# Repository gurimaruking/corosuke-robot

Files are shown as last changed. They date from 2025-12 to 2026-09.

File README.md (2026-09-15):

# 🤖 Corosuke Robot / コロ助ロボット

> **C**ommunication-**O**riented **R**obot for **O**bserving, **S**upporting, and **U**nderstanding **K**ids' **E**veryday — that's **COROSUKE**.







A ~46 cm open-source animatronic of **Korosuke (コロ助)** from *Kiteretsu Daihyakka* — he
sees, listens, thinks, and talks in **Japanese or English**, emotes through his eyes, waves
his arms, and shuts himself down safely. Everything runs **100 % on-device on a D-Robotics
RDK X5**, with an ESP32-S3 driving the eyes and arms.

> 🏆 **D-Robotics Robotics Dream Keeper Challenge — Stage 3 (Launch)**
> 📄 [STAGE3.md](STAGE3.md) — showcase & benchmarks · 🧩 [PROPOSAL.md](PROPOSAL.md) · 🗺 [ROADMAP.md](ROADMAP.md)

<p align="center">
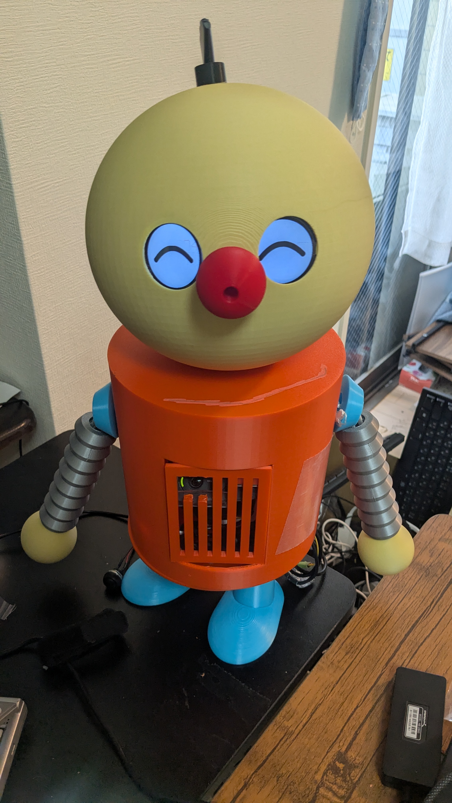
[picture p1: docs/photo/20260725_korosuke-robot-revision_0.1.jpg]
Corosuke revision 0.1 — fully assembled, smiling
  
</p>

## ▶ Watch the demo

<p align="center">
  <a href="https://youtu.be/NJwj6Iazd20">
    Watch the Corosuke demo on YouTube
  </a>
  <br>
  <a href="https://youtu.be/NJwj6Iazd20">
    
  </a>
</p>

---

## What it does

Powered on and left alone, Corosuke wakes and greets you, tracks you with BPU pose
detection, holds a conversation (on-device STT → LLM → TTS, with a "thinking" eye animation
while he ponders), reacts to gestures, waves his arms, and shuts down safely on a button
press (goodnight voice → ✕✕ "safe-to-unplug" eyes). A tabbed **web dashboard** at
`http://<board-ip>:8080` streams the live camera + skeleton and tunes every setting.

| Subsystem | Implementation | Measured |
|---|---|---|
| Vision | BPU YOLO11n-pose (Bayes-e `.bin`) | ~19.5 FPS |
| Speech-to-text | sherpa-onnx **SenseVoice** (JP/EN) + Silero VAD | real-time (CPU) |
| LLM dialogue | llama.cpp + TinySwallow-1.5B *(Qwen2.5-1.5B-based)* — JP & EN personas | 1.5–3.3 tok/s · ~5–10 s/reply |
| Text-to-speech | **JP** Open JTalk / **EN** espeak-ng | instant |
| Language | **日本語 / English** — STT · LLM · TTS · Web UI, switchable on the fly | on-device |
| Audio out | **MAX98357A I2S amp** (custom kernel driver) → φ50 speaker | DSP-tuned |
| Eyes | 2× GC9A01 on ESP32-S3 — 8 emotions (smile / thinking / ✕✕) | ≥30 FPS |
| Arms | 2× SG90 rope-pull bellows arms | auto-detach |

> 🌐 **Bilingual & fully on-device.** One switch flips the whole robot — speech recognition,
> LLM replies, voice, *and* the dashboard — between **Japanese and English**, with **no cloud
> and no API keys**. The voice stack follows D-Robotics' own [RDK voice-interaction
> reference](https://developer.d-robotics.cc/magicbox_doc/en/algorithm-development/voice-interaction):
> **SenseVoice** ASR + a **Qwen2.5-1.5B**-family LLM (we run the Japanese-tuned
> **TinySwallow-1.5B** via llama.cpp on CPU).

### Build tools & jigs

To reproduce the body you'll also need:

| Tool | Purpose | Where to get |
|---|---|---|
| **Velcro tape** | attaching parts to the 3D-printed body | [Amazon](https://www.amazon.co.jp/dp/B0GJZJM4TG) |
| **Ultrasonic cutter** (or an alternative) | post-processing the 3D-printed parts — anything that melts plastic works, even a heated metal needle | AliExpress |
| **3D printer** | printing the parts! (we used a **Bambu Lab A1**; parts are within 18 cm, so an **A1 mini** should *just* fit) | — |
| **Double-sided tape** | bonding parts | — |
| **String** | moving the hands (rope-pull arms) | — |
| **Zip ties** | tuning the rope arms | [Daiso](https://jp.daisonet.com/products/4550480088891) |
| **Soldering iron** | a little soldering (power button, amp terminals, etc.) | — |
| **Breadboard** (small) | ESP32-S3 wiring | — |
| **Jumper wires** (M-M / M-F) | connecting the parts | — |

## Challenge journey — Stage 1 → 2 → 3

| Stage | Theme | What was proven | Doc |
|---|---|---|---|
| **1 — Ideation** | On-device perception | YOLO11 vision on the **RDK X5 BPU** (+ open-source [RDK X5 case](https://github.com/gurimaruking/rdk-x5-modular-case)) | [STAGE1.md](STAGE1.md) |
| **2 — Build** | System design | The **RDK X5 as the single cognitive core** under a **ROS 2 graph**; ESP32s become actuator sub-controllers | [PROPOSAL.md](PROPOSAL.md) |
| **3 — Launch** | Shipped robot | The full interactive Corosuke — sees / listens / thinks / talks / emotes, **bilingual**, 100 % on-device (this repo) | [STAGE3.md](STAGE3.md) |

Stage 1's BPU vision is still today's perception layer, and Stage 2's ROS 2 design ships as
[`ros2_ws/`](ros2_ws/) alongside the low-latency monolith.

## Quick start (on the RDK X5)

> All on-device. **No cloud, no API keys.** Perception on the BPU, dialogue on the CPU.

```bash
# 1) Clone
git clone https://github.com/gurimaruking/corosuke-robot.git && cd corosuke-robot

# 2) Flash the eye/arm co-MCU (ESP32-S3) — from the RDK X5 (uses the CH343 UART port)
cd firmware/corosuke_eyes && pio run -t upload && cd ../..

# 3) One-time: MAX98357A I2S amp — build the out-of-tree codec driver + device-tree overlay
#    Follow docs/rdk_x5_40pin_i2s_max98357a.md  (kernel headers are already on the board)

# 4a) Run the INTEGRATED demo (monolithic, low-latency) as a systemd service
sudo cp deploy/*.service /etc/systemd/system/
sudo systemctl daemon-reload && sudo systemctl enable --now korosuke-monitor korosuke-shutdown-btn
#     → open  http://<board-ip>:8080   (Monitor / Settings tabs)

# 4b) — or — run the MODULAR ROS 2 graph (same on-device stack: TinySwallow + Open JTalk, no cloud)
cd ros2_ws && colcon build && source install/setup.bash
ros2 launch korosuke_nodes korosuke.launch.py                  # vision → brain → eyes / dialogue → voice
ros2 launch korosuke_nodes korosuke.launch.py with_web:=true   # + rosbridge :9090 → open ros2_ws/src/korosuke_nodes/web/console.html
#   NB: eye path is HW-verified; full graph is code-complete but not yet run end-to-end (see STAGE3 §5.1)

# Safe shutdown:  hold the GPIO button ~1 s  → goodnight voice → ✕✕ eyes → OS halt → cut power.
```

**Models** (STT / LLM / YOLO `.bin`) download on the board — see
[stt_research.md](docs/stt_research.md) and [dialogue_stack_research.md](docs/dialogue_stack_research.md).
The LLM stays on the CPU **by design**: the X5 BPU cannot accelerate LLMs
([rdk_x5_bpu_llm.md](docs/rdk_x5_bpu_llm.md)), so replies take ~5–10 s — the "thinking" eyes
cover the wait.

## Repository layout

```
corosuke-robot/
├── STAGE3.md, PROPOSAL.md, ROADMAP.md   # showcase / Stage-2 design / roadmap
├── scripts/            # korosuke_monitor.py (integrated demo) · shutdown_button.py · fix_max98357a.sh
├── ros2_ws/            # ROS 2 graph: korosuke_msgs + korosuke_nodes (vision/brain/dialogue/voice/serial_bridge)
├── firmware/           # ESP32-S3 (PlatformIO): corosuke_eyes (eyes + arms) · max98357a (I2S driver)
├── deploy/             # systemd units + sudoers (auto-start, safe shutdown, audio self-heal)
├── hardware/3d_models/ # OpenSCAD body (color-split) + RDK X5 modular case
└── docs/               # architecture, audio(I2S), BPU-LLM, network, power/USB, research, photos, diary
```

## Documentation

- **[STAGE3.md](STAGE3.md)** — architecture (Mermaid), benchmarks, **known issues & limitations**, requirement coverage
- **Story / presentation** — intro blog [日本語](docs/blog/intro_ja.md) · [English](docs/blog/intro_en.md) · 5-min talk: [slides PDF](docs/slides/talk_5min.pdf) · [deck (PNG)](docs/slides/talk_5min_deck.md)
- Audio (I2S amp): [docs/rdk_x5_40pin_i2s_max98357a.md](docs/rdk_x5_40pin_i2s_max98357a.md) · [firmware/max98357a/](firmware/max98357a/)
- Why the LLM stays on CPU: [docs/rdk_x5_bpu_llm.md](docs/rdk_x5_bpu_llm.md)
- Network / maintenance: [docs/network_setup.md](docs/network_setup.md) · Power/USB brown-out: [docs/power_usb_troubleshooting.md](docs/power_usb_troubleshooting.md)
- Testing: [docs/TESTING.md](docs/TESTING.md) · Build log: [docs/diary/](docs/diary/)

## Credits & inspiration

Corosuke's design borrows ideas from these open / animatronic robots:

- [Disney's Olaf robot](https://thewaltdisneycompany.com/olaf-robotic-character/) — expressive animatronic eyes & face
- [Open Duck Mini (BDX)](https://github.com/apirrone/Open_Duck_Mini) — compact bipedal droid
- [3D-printed animatronic dual-eye mechanism](https://www.instructables.com/Simplified-3D-Printed-Animatronic-Dual-Eye-Mechani/) — the eye-rig approach

## License & disclaimer

MIT for the code/hardware — see [LICENSE](LICENSE). Fan-made, **non-commercial** tribute:
"Korosuke" (コロ助) is a character from *Kiteretsu Daihyakka* by Fujiko F. Fujio; all
character rights belong to their respective owners.

**「ワガハイはコロ助ナリ！」** 🤖

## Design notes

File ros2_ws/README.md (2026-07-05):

# Korosuke ROS 2 workspace (RDK X5 cognitive core)

Stage 3 の実装。RDK X5 (ROS 2 Humble) を頭脳に、コロ助が
**見る → 追う → 挨拶する → 表情/声で反応する** をオンデバイスで動かす。

## パッケージ
| pkg | 中身 |
|---|---|
| `korosuke_msgs` | `EyeCmd`(emotion/gaze/blink), `FacePose`(detected/x/y/size) |
| `korosuke_nodes` | `vision`(BPU YOLO11n→/face_pose), `brain`(追従+挨拶), `serial_bridge`(→ESP32目UART), `dialogue`(Claude+「ナリ」), `voice`(VOICEVOX), `eye_demo`(M2実証) |

## データフロー
```
camera ─► vision_node ─/face_pose─► brain_node ─/eye_cmd──► serial_bridge ─UART─► ESP32-S3(目)
                                        └────────/greet──► dialogue_node ─/say_text─► voice_node ─► spk
                                                             └─────────/eye_cmd──────► serial_bridge
```

## ビルド
```bash
source /opt/ros/humble/setup.bash
cd ~/corosuke/ros2_ws
colcon build --symlink-install
source install/setup.bash
```

## 実行
```bash
# 全部まとめて
ros2 launch korosuke_nodes korosuke.launch.py

# 目だけ動作実証(M2, カメラ/LLM不要)。ESP32-S3をUSB接続してから:
ros2 run korosuke_nodes serial_bridge &
ros2 run korosuke_nodes eye_demo

# 手入力でコロ助と会話(STT代わり)
ros2 topic pub --once /korosuke/user_text std_msgs/String "{data: 'コロッケ好き？'}"
```

## 前提
- `ANTHROPIC_API_KEY` を export すると LLM 応答。無ければ定型「ナリ」応答。
- VOICEVOX を `localhost:50021`(または `VOICEVOX_HOST`)で起動すると発声。無ければセリフ表示のみ。
- 目: `firmware/corosuke_eyes` を焼いた ESP32-S3 を USB 接続(テキスト行 115200bps)。

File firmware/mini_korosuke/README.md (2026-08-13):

# firmware/mini_korosuke — ミニコロ助 (ESP32-S3 単体 / 完全オフライン)

[docs/mini_korosuke_design.md](../../docs/mini_korosuke_design.md) の実装。
ベースボード = **Elecrow ESP Terminal 3.5"**（ESP32-S3, 320×480 ILI9488 SPI, 静電容量タッチ FT6236, OV2640 同梱, 16MB/8MB）。

目の描画は本体の [firmware/corosuke_eyes](../corosuke_eyes/src/main.cpp) から移植（丸型GC9A01×2 → 単画面ILI9488に左右2目）。

## フェーズ
| Ph | 内容 | 本ファイルの状態 |
|----|---|---|
| **Ph1** | 単画面に左右2目＋表情8種＋まばたき＋視線（デモ巡回） | ✅ `src/main.cpp` |
| Ph2 | 静電タッチ(なで)→笑顔＋MAX98357A(I2S)でWAV再生 | ⏳ 未 |
| Ph3 | OV2640＋ESP-WHO顔検出→視線追従＋発見で笑顔 | ⏳ 未 |

## ピン割り当て
**確定（Elecrow wiki）**
| 機能 | ピン |
|---|---|
| SD (SPI) | SCK=12 MOSI=13 MISO=14 CS=10 |
| Touch FT6236 (I2C) | SDA=2 SCL=1 |
| Buzzer | 45 |
| Mic (I2S) | CLK=39 WS=38 |
| Camera OV2640 | MCLK=7 PCLK=17 / D2..D9=8,47,48,21,18,16,15,6 |
| Crowtail | D=11,40 / A=19,20 / UART RX=44 TX=43 |

**★未確定（実機スキーマで要確認）— `src/main.cpp` 冒頭の `PIN_LCD_*`**
- LCD ILI9488 の **CS / DC / RST / BL**。本S3+カメラ版の確定値が未取得。
- LCDはSDと同一SPIバス（SCK12/MOSI13/MISO14）を共有する前提で設定済み。
- ネット上に出回る `CS15/DC2/BL27` は**旧ESP32(非S3)版**の値。**DC=2 は本機の Touch SDA=2 と衝突**するので流用不可。
- 現状の `PIN_LCD_CS=3 / DC=42 / RST=-1 / BL=46` は「確定ピンと衝突しない仮値」。**ボード到着後に必ず実測して修正**すること。

**Ph2の音声増設（予定）**: 在庫の MAX98357A を I2S で Crowtail の空きGPIO（D=11,40 ＋ A=19 等）へ。BCLK/LRCLK/DIN の3本。

## ビルド & 書き込み
```bash
pio run -e elecrow-esp-terminal-35 -t upload
pio device monitor -b 115200
```
※ ★未確定ピンを埋める前は正しく表示されない。まず `PIN_LCD_*` を実機で確定させること。

## シリアルコマンド（USB-CDC / 115200・センサ無しで動作確認可）
```
emo <neutral|happy|happy2|sad|angry|surprised|sleepy|thinking|x>
gaze <x> <y>     # -1.0..1.0
blink
wink <l|r>
idle <on|off>
demo <on|off>    # 表情8種を自動巡回(初期ON)
ping             # -> pong
```

## 音声クリップの用意（別途・PC/RDK側）
声質はコロ助と同一（`-fm 9 -a 0.40 -r 1.12`）。Open JTalk のある環境で:
```bash
python3 ../../tools/mini_voice_gen.py            # WAV + manifest.json + include/voice_clips.h を生成
python  ../../tools/mini_voice_gen.py --dry-run  # Windows等: 先にヘッダ/マニフェストだけ
```
生成物: `assets/mini_voice/*.wav`（microSDの `/voice/` に配置）と `include/voice_clips.h`（Ph2でincludeして使用）。

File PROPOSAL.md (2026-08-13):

# Project Korosuke — Stage 2 (Build): System Design

D-Robotics **Robotics Dream Keeper Challenge** — Stage 2 design document.
Korosuke (コロ助) is the samurai-robot from *Kiteretsu Daihyakka*, rebuilt as a
50 cm desktop animatronic whose brain is an **RDK X5** (10 TOPS BPU, ROS 2).

> **Status:** v1.0 (2026-07-05, submitted). Builds directly on the Stage 1 result
> ([STAGE1.md](STAGE1.md)) — on-device YOLO11 vision is already proven.
> **Key pivot documented here:** the original design (3× ESP32 + a home server
> doing the AI) is **re-wired** so the RDK X5 is the cognitive core and the ESP32s
> become its servo/actuator sub-controllers, all under a ROS 2 graph.
>
> ⚠️ **This is the Stage-2 *plan*, not the shipped robot.** Some proposed subsystems
> were **deferred / not built** — notably the **2-axis mouth & lip-sync**, the **neck servo**
> (gaze is eyes-only), **bipedal QDD walking** (stretch), and VOICEVOX was replaced by
> on-device Open JTalk TTS. See **[STAGE3.md §8](STAGE3.md#8-known-issues-limitations--failure-recovery)**
> for exactly what shipped vs. what was deferred.

---

## 1. Concept

### 1.1 What Korosuke does
A child-minded samurai robot that **sees, talks, emotes, and gestures** — and, as a
stretch, **walks**. He recognizes a person, turns to look, greets them in his
trademark "…nari" speech, shows emotion through large animated eyes, and reacts
with head/arm gestures. All perception and dialogue run **on-device** on the RDK X5.

### 1.2 Why RDK X5 at the center (the Stage-1 pivot)
The pre-challenge design pushed AI to an external home server and used 3 ESP32s as
peers. Stage 1 proved the RDK X5 can run the perception **on the board** (YOLO11n on
the BPU). Stage 2 therefore promotes the RDK X5 to the **single cognitive core** and
demotes the ESP32s to **dumb, real-time actuator drivers** it commands. This removes
the network round-trip from the perception loop and gives a clean ROS 2 architecture.

### 1.3 Measurable goals (acceptance criteria)
Grounded in Stage 1 measurements (live USB-cam YOLO11n **8.3 FPS end-to-end**, BPU
alone **~67 inferences/s**, idle **66 °C → ~49 °C** with the fan lid):

| # | Capability | Target (measurable) | Stage-1 basis |
|---|---|---|---|
| G1 | Vision (person/face) | ≥ 10 FPS sustained on BPU; detection→action latency < 150 ms | 8.3 FPS live, 67 FPS BPU headroom |
| G2 | Gaze / head tracking | Eyes + neck follow a face, error < 5° after 300 ms | new |
| G3 | Voice dialogue | wake → LLM → speech start < 3.0 s; "…nari" style 100% | server already implemented |
| G4 | Lip-sync | mouth follows audio envelope within 100 ms | protocol has LIPSYNC_DATA |
| G5 | Eye emotion | ≥ 30 FPS render on 2× GC9A01, 7 emotions | RoboEyes-class |
| G6 | Thermal under load | BPU+CPU+vision sustained < 60 °C | 50 °C @ 20 s BPU load (fan) |
| G7 | *(stretch)* Bipedal | quasi-static "penguin" gait, 3+ steps, no fall | QDD revival gated |

---

## 2. AI System Architecture

### 2.1 End-to-end data flow

```mermaid
flowchart LR
  CAM[USB / MIPI camera] --> VIS

  subgraph RDKX5["RDK X5 — cognitive core (Ubuntu 22.04 + ROS 2)"]
    VIS["vision_node<br/>BPU: YOLO11n + face"]
    BRAIN["ai_brain_node<br/>state machine + intent"]
    LLM["dialogue_node<br/>LLM (Claude/OpenAI) + 'nari' persona"]
    TTS["voice_node<br/>VOICEVOX (Zundamon) + lipsync envelope"]
    EXP["expression_node<br/>emotion -> eye/mouth cmds"]
    MOT["motion_node<br/>gaze + gesture + (stretch) gait"]
    BRIDGE["serial_bridge_node<br/>ROS2 <-> UART 0xAA..0x55"]
    MIC[I2S mic] --> LLM
    TTS --> SPK[I2S speaker/amp]
  end

  VIS -->|/person, /face_pose| BRAIN
  BRAIN --> LLM
  BRAIN --> MOT
  LLM --> TTS
  LLM -->|emotion| EXP
  TTS -->|/lipsync| EXP
  EXP --> BRIDGE
  MOT --> BRIDGE

  BRIDGE -->|UART| EYE["ESP32-S3 — eye coprocessor<br/>2× GC9A01 (RoboEyes)"]
  BRIDGE -->|UART| UP["ESP32 — upper body<br/>PCA9685: mouth/neck/arms"]
  BRIDGE -->|UART| LO["ESP32 — lower body<br/>servo/QDD + BNO055 IMU"]
  LO -->|/imu, /balance| BRAIN
```

### 2.2 ROS 2 node / topic graph

```mermaid
flowchart TD
  vision["/korosuke/vision_node"] -->|sensor_msgs/Image, vision_msgs/Detection2DArray| brain
  vision -->|geometry_msgs/PointStamped /face_pose| motion
  brain["/korosuke/ai_brain_node"] -->|std_msgs/String /intent| dialogue
  brain -->|/gaze_target| motion["/korosuke/motion_node"]
  dialogue["/korosuke/dialogue_node"] -->|/say_text| voice
  dialogue -->|/emotion| expression
  voice["/korosuke/voice_node"] -->|/lipsync_env| expression
  expression["/korosuke/expression_node"] -->|korosuke_msgs/EyeCmd, MouthCmd| bridge
  motion -->|korosuke_msgs/ServoCmd, GaitCmd| bridge
  bridge["/korosuke/serial_bridge_node"] -->|UART frames| mcus["ESP32 ×3 (eye/upper/lower)"]
  mcus -->|/imu, /status| bridge --> brain
```

**Custom messages** (`korosuke_msgs`): `EyeCmd` (gazeX, gazeY, emotion, blink),
`MouthCmd` (open 0-1), `ServoCmd` (joint id, angle), `GaitCmd` (step, dir),
`Detection` (label, score, bbox). The existing **`protocol.h` (0xAA…0x55)** frame
is kept as the wire format; `serial_bridge_node` serializes ROS 2 msgs to it, so
the ESP32 firmware barely changes.

### 2.3 Compute & resource allocation

RDK X5 = 8× Cortex-A55 (CPU), 10 TOPS BPU, 8 GB LPDDR4, Mali GPU.

| Engine | Workload | Budget | Notes |
|---|---|---|---|
| **BPU** | YOLO11n detection (+ face crop/landmarks) | ~15 % of 67 FPS headroom at 10 FPS | model already converted (Bayes-e .bin) |
| **CPU core 0-1** | ROS 2 DDS + node executors | moderate | Cyclone DDS |
| **CPU core 2-3** | dialogue_node (async LLM HTTP) + persona | I/O-bound | reuse `server/` code |
| **CPU core 4** | voice_node: VOICEVOX client + audio I2S + lipsync envelope | real-time audio | MAX98357A out, INMP441 in |
| **CPU core 5** | motion_node: gaze/gesture planning, (stretch) gait | light | |
| **CPU core 6-7** | serial_bridge + headroom | low | 3× UART @ 115200 |
| **ESP32-S3 (eyes)** | 2× GC9A01 @ ≥30 FPS, RoboEyes | dedicated MCU | off-loads display from RDK |
| **ESP32 (upper)** | PCA9685 #1: mouth/neck/arms, 50 Hz | dedicated MCU | existing firmware |
| **ESP32 (lower)** | servo/QDD + BNO055 100 Hz balance | dedicated MCU | existing skeleton |

**Thermal:** sustained BPU+CPU stays < 60 °C with the open-source **fan lid**
(5 V 40 mm fan off the 40-pin header) — validated in Stage 1.

---

## 3. Engineering Plan

### 3.1 Bill of Materials (summary)
This table is the canonical BOM. As-built hardware deltas for the shipped robot (φ50 speaker on a MAX98357A I2S amp, Logitech C270 camera, safe-power button, mic taken from the C270) are in [STAGE3.md](STAGE3.md).

| Subsystem | Part | Qty | Status |
|---|---|-----|---|
| Brain | RDK X5 8GB + open-source fan case | 1 | ✅ owned / case done |
| Eyes | GC9A01 1.28" 240×240 SPI | 2 | to buy (~¥2.4k) |
| Eye coproc | ESP32-S3 N16R8 | 1 | to buy (~¥2.5k) |
| Camera | UVC USB (Stage 1) → MIPI CSI (planned) | 1 | ✅ working |
| Face/neck/arms | PWM servos (SG90/MG996R) + PCA9685 ×2 | ~12 + 2 | ✅ in stock |
| Audio | INMP441 mic, MAX98357A amp + speaker | 1 set | ✅ in stock |
| IMU | BNO055 | 1 | ✅ in stock |
| Touch (head-pat) | TTP223 capacitive touch sensor | 1 | 🔜 planned — not yet installed |
| Body display (STT/reply view) | ESP32 CYD — Sunton ESP32-4827S043R 4.3" touch *(or ESP32-1732S019 1.9", auto-detected)* | 1 | ✅ working — shows camera + recognized speech + replies, language switch on touch |
| Legs *(stretch)* | SteadyWin GIM8108-36 QDD (CAN) | ≤8 | ⚠️ junk, unverified |
| Power | LiPo 3S/4S + DC-DC + AC adapter | — | ✅ in stock |

### 3.2 Proposed repository layout
```
corosuke/
  ros2_ws/src/                # NEW — the cognitive core
    korosuke_msgs/            # EyeCmd, MouthCmd, ServoCmd, GaitCmd, Detection
    korosuke_vision/          # BPU YOLO11 + face -> /person, /face_pose
    korosuke_brain/           # state machine + intent
    korosuke_dialogue/        # LLM + persona (port of server/corosuke_personality.py)
    korosuke_voice/           # VOICEVOX client + audio I/O + lipsync
    korosuke_expression/      # emotion -> eye/mouth
    korosuke_motion/          # gaze/gesture/(gait)
    korosuke_bridge/          # ROS2 <-> protocol.h UART
  firmware/                   # EXISTING — minor refactor (eye/upper/lower)
  server/                     # EXISTING — folded into korosuke_dialogue/voice
  hardware/3d_models/         # EXISTING — body + RDK X5 case
  docs/                       # this design, BOM, inventory, research
```

### 3.3 Roadmap (as of 2026-07-05 → hard deadline 2026-07-15)

**Done so far:** Stage 1 (BPU YOLO11 vision, thermal fan-lid, open-source RDK X5
case) ✅; full 3D body redesigned for color-split printing ✅; eye coprocessor
firmware flashed (2× GC9A01 on ESP32-S3, LovyanGFX) ✅; chest stereo-camera mount
designed ✅. See the live plan in [ROADMAP.md](ROADMAP.md).

| Window | Milestone | Exit criterion |
|---|---|---|
| **7/5–7/7** | ROS 2 Humble on RDK X5; `korosuke_msgs`; `serial_bridge` ↔ ESP32-S3 eyes | a ROS 2 topic makes the eyes blink / change emotion |
| **7/8–7/11** | `vision_node` (BPU) → `/face_pose`; gaze (eyes + neck) tracking; on-device dialogue loop (LLM + VOICEVOX) + lipsync; `expression_node` | Korosuke looks at a face and says a "…nari" line with lipsync |
| **7/12–7/13** | Integrated demo: see → turn → greet → emote → gesture, fully on-device; benchmark table (FPS / latency / thermal) | G1–G6 met; **competition-critical line complete** |
| **7/14–7/15** | 3–7 min demo video; Stage 3 showcase PR; bipedal stretch *iff* QDD revived | Stage 3 submission package |

### 3.4 Risk analysis

| # | Risk | Likelihood | Impact | Mitigation |
|---|---|---|---|---|
| R1 | **QDD GIM8108 are junk / dead** | high | high (no walking) | Bipedal is a **decoupled stretch**, never on the MVP critical path; MVP passes on a seated/standing torso |
| R2 | LLM/VOICEVOX latency or network drop | med | med | local response cache, canned "…nari" fallbacks, keep dialogue async off the perception loop |
| R3 | 2× GC9A01 @30 FPS too heavy for one MCU | med | med | dedicated **ESP32-S3 coprocessor** (not the RDK); RoboEyesTFT; drop to 240×240@30 per eye |
| R4 | Thermal throttling under multi-task | low | med | fan lid validated (−17 °C); monitor `hrut_somstatus` |
| R5 | Eye looks small (φ32 LCD in a 50 mm socket) | med | low | white diffuser ring + recessed mount in `corosuke_exterior.scad` |
| R6 | RoboEyes is **GPL-3.0** | low | med (licensing) | isolate eye firmware as a separate GPL component; keep core under its own license |
| R7 | Power budget if QDD added (high stall current) | med | med | separate LiPo rail + DC-DC (see BOM §3.1); current-limit; MVP runs on bench PSU |
| R8 | Timeline (7/8 is tight) | med | high | MVP-first decoupling; reuse existing firmware/server; this plan front-loads integration |

---

## 4. Reuse vs. new work

| Asset | Stage 1/pre status | Stage 2 action |
|---|---|---|
| `protocol.h` / `config.h` | complete | **reuse** as the RDK↔ESP32 wire format |
| `firmware/corosuke_main` | done (WiFi/cam/LLM) | **retire** — its brain role moves to RDK X5 |
| `firmware/corosuke_upper/lower` | skeletons | **refactor** into pure ROS2-driven servo nodes |
| `server/` (FastAPI+LLM+VOICEVOX) | done | **port** into `korosuke_dialogue`/`korosuke_voice` on-device |
| `corosuke_personality.py` ("…nari") | done | **reuse** verbatim |
| 3D body + RDK X5 case | done | **reuse**; only the eye socket needs tuning |
| BPU YOLO11n pipeline | proven (Stage 1) | **promote** into `vision_node` |

The heavy lifting is **re-wiring, not re-inventing** — most subsystems already exist;
Stage 2 puts the RDK X5 in charge and expresses the whole system as a ROS 2 graph.

---

*Assumptions to confirm with the team:* exact servo counts per joint (pending the
actuator-assignment table), whether the home server stays as a fallback or is fully
folded on-device, and the bipedal go/no-go once the QDD motors are bench-tested.

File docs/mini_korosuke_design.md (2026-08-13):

# ミニコロ助 — ESP32-S3 単体 設計書

**完全オフライン**で動く手のひらサイズの「コロ助」。RDK X5 を使わず **ESP32-S3 1枚**で
目の表情・なで反応・顔検出・「〜ナリ」音声までを完結させる派生機。
本体（[stage2_design.md](stage2_design.md)）の資産を **流用中心**で再構成する。

> 決定日: 2026-07-29 / 方針: 完全オフライン（no cloud・ネット不要）

---

## 1. スコープ（確定）

| 項目 | 決定 |
|---|---|
| しゃべり方式 | **完全オフライン**。LLM/STT/TTS は載せない（S3では不可能）。事前生成した「〜ナリ」WAV を再生 |
| 搭載機能 | 目の表情8種 ◎ / なで（タッチ）反応 ◎ / **カメラ顔検出→視線追従** |
| 見る | **あり**（カメラ付きS3ボードを使用） |
| 非搭載（今回） | 会話、音センサ反応（マイクは載るが未使用）、腕サーボ |
| ネット | 一切不要（ボード net不通・no cloud 原則を満たす） |

**S3単体で動かせない物（明示）:** TinySwallow-1.5B LLM / sherpa-onnx STT /
Open JTalk・VOICEVOX TTS。いずれも RDK/PC の CPU 前提。ミニ版は声を**事前生成**で回避する。

---

## 2. ハードウェア

### 2.1 ベースボード（推奨）
**Elecrow ESP Terminal 3.5"（OV2640 同梱）**

| 項目 | 実機仕様 | 備考 |
|---|---|---|
| MCU | ESP32-S3 / 16MB Flash / 8MB PSRAM | 目描画＋顔検出＋音声に十分 |
| 画面 | 3.5" 320×480 **ILI9488** SPI TFT | 1枚に左右2目を描く |
| タッチ | 静電容量式 | 「なで」＝画面タッチに割当 |
| カメラ | **OV2640 2MP 同梱** | 顔検出（ESP-WHO/esp-dl） |
| マイク | MEMS マイク搭載 | 今回未使用（将来の手拍子反応に流用可） |
| 音声出力 | **ブザーのみ**（アンプ/SP無し） | ⚠️ 音声には別途 I2S アンプが必要 |
| 拡張 | Crowtail×6（2×Analog / 2×Digital / 1×UART / 1×I2C）, SDスロット, LiPo | I2S は空きGPIOへ |

### 2.2 追加部品（買い足しほぼゼロ）
- **MAX98357A ＋ 小型スピーカー**（在庫あり）— I2S で増設。**ブザーでは「〜ナリ」音声は鳴らせない**ため必須
- microSD（音声クリップ格納、小容量で可）
- Elecrow ESP Terminal 3.5" 本体（要購入・$40前後）

### 2.3 配線メモ（ボード到着後に確定）
- I2S(MAX98357A): BCLK/LRCLK/DIN の3本を Digital Crowtail の空きGPIOへ。実ピンは Elecrow pinout で確定する。
- 音声とカメラ(DVP)・LCD(SPI)・タッチ(I2C) のGPIO衝突がないことを配線時に確認。

---

## 3. ソフトウェア構成（流用マップ）

| ミニ版の要素 | 元ネタ | 作業量 |
|---|---|---|
| 表情8種の描画 | `firmware/corosuke_eyes/src/main.cpp` `renderEye()` | 流用。丸型2枚→単画面に2つ描く座標変更 |
| まばたき/視線補間/アイドル | 同 `loop()` | ほぼ流用 |
| ディスプレイ駆動 | LovyanGFX（GC9A01→**ILI9488**へパネル差替） | ドライバ設定変更 |
| なで検知 | 同 touchRead(GPIO6) | **静電タッチスクリーン**へ置換 |
| 台本・感情・「〜ナリ」 | `ros2_ws/.../personality.py` `EXPRESSION_KEYWORDS`/`EYE_EMOTION` | 定型セリフを C++ テーブル化 |
| 声質 | personality.py `OJ_FM=9 / OJ_A=0.40 / OJ_R=1.12` | PC側 Open JTalk で WAV 事前生成→SD |
| 顔検出→視線 | 新規（ESP-WHO human_face_detect） | S3完結。bbox中心→`gaze` に写像 |

- 目の描画は**自作コード**（RoboEyes 不使用）＝ stage2 R6 の GPL 懸念なし。
- 感情は本体と同じ 8 種（neutral/happy/happy2/sad/angry/surprised/sleepy/thinking/✕✕）。

### 3.1 自律ふるまいエンジン（新規・S3側）
本体では RDK が感情を決めていたが、ミニ版は S3 が自分で決める：
- アイドル：まばたき＋視線ゆらぎ（既存流用）
- 顔を検出：その方向へ視線→数百ms後に happy ＋ 挨拶WAV
- なで（画面タッチ）：happy ＋ 反応WAV（1.2s デバウンス、既存踏襲）
- ランダム：たまに thinking / sleepy など小芝居＋短いWAV

---

## 4. ロードマップ

| Ph | 内容 | 完了条件 |
|----|---|---|
| Ph0 | 準備（ボード待ちでも可）：Open JTalk「〜ナリ」WAV一式生成＋PlatformIO雛形(ILI9488) | WAVがPCで鳴る／空プロジェクトがビルド通る |
| Ph1 | 顔：単画面に左右2目＋表情8種＋まばたき | 8表情が画面で切り替わる |
| Ph2 | なで＆声：静電タッチ→笑顔＋MAX98357AでWAV再生 | 画面をなでると笑って「〜ナリ」と言う |
| Ph3 | 見る：OV2640＋ESP-WHO顔検出→視線追従＋発見で笑顔 | 人が動くと目が追い、見つけて笑う |
| Ph4 | 外装：3.5"を顔にする小型筐体（hardware/3d_models 流用縮小） | 卓上で自立する見た目 |

---

## 5. 未確定・確認事項
- Elecrow ESP Terminal の I2S 用空きGPIO（実ピン）— ボード到着後に pinout で確定
- ILI9488(SPI) で左右2目を ~30fps 描けるか（PSRAM スプライト＋部分更新で対応見込み）
- ESP-WHO 顔検出のフレームレート（数fps想定、視線追従には十分）
- 音声クリップの格納先：SD か 16MB Flash 内蔵か（本数と容量で決める）

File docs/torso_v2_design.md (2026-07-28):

# 胴体 v2 設計 — 実装レイアウト再設計 (2026-07-27)

ソース: [hardware/3d_models/korosuke_print/torso_v2.scad](../hardware/3d_models/korosuke_print/torso_v2.scad)
外形は v1 `jacket_shell` と互換（H165 / 裾φ158 / 上φ165 / 壁3、ハッチ・ボタン穴・腕穴・グリル同位置）。
**頭・襟・背面パネル・腕・脚は v1 のまま使えます。**

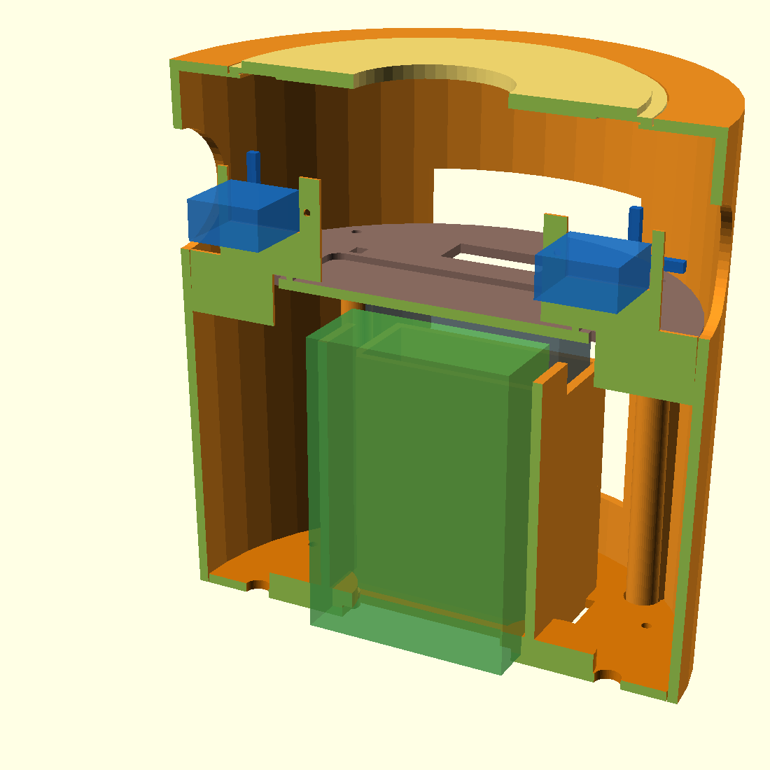
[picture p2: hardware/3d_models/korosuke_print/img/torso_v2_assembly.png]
assembly


## 要件 → 実装

| 要件 | 実装 |
|---|---|
| SG90×2 でロープアームを引く（ネジ止め） | **壁沿いコの字クレードル**（deck上z106-136・シェル側壁に融着）。**十字ホーン対応**: 軸(±58,z126)・ホーン面を背面の後ろ(y3)に置き十字はタワー後方で旋回=タワーと不干渉。掃引円(半径16)は外壁4.7mm/デッキ5.0mmクリア（数式検証済）。本体を上から落とし込み→内側タブM2×1（軸端を外=腕穴側へ・左右逆）。ホーンは「上〜内側」のみ使用 |
| RDK X5 筐体が入る | v1 と同じ **縦置きレール**（91.4×62.4×27.1 +遊び1mm、前面寄り）。**横出しジャンパ用に上下+5mm余裕**（底上げ5mm標準オフ+側面レール短縮） |
| モバイルバッテリー | 背面に **縦置きトレイ**（既定 62×24、`PB_W/PB_T` で変更可）。上開放・底板にベルクロスロット |
| ESP32-S3 & ブレッドボード | **頭部に移設**（2026-07-28決定）。中段デッキは**上から物を入れる棚**として存続（ブレッドボード枠は将来用に温存） |
| 上から物を入れる | 天板廃止 → **φ118 開口 + 落とし込みリッド**（首穴φ46・指掛かり2箇所）。頭ごと持ち上げれば胴内デッキに手が届く |
| USB 4本を下から出す | 底板に **RDK窓 56×24 / バッテリー窓 / 背面スロット**。フットベースにも同位置の窓＋**裏面排線溝**（ベタ置きのまま背面へ） |
| 胸カメラ | 前面 z=100 に **32×32/38×38 UVC基板ポケット**（M2ボス×4・ピッチ28、10°上向き）＋ **レンズ窓φ12＋すり鉢面取り**（M12レンズ先端φ10・100°ケラレ防止）＋マイク導音孔×3 |
| スピーカー | 秋月 [WYGD50D-8-03](https://akizukidenshi.com/catalog/g/g109012/) **φ50×18.5mm**（8Ω/0.2W）。前面グリル裏の座リング（φ50.6落とし込み+音抜きφ44+結束穴）に前面から嵌める。厚み18.5mmは内側へ突出=RDK/デッキと非干渉 |
| フットベース | 現状アクリル両面テープ固定 → v2 は **裾ズレ止め土手＋テープゾーン＋M3×4 共締め穴**（皿もみ）。両面テープ運用のままでも可 |

## パーツ一覧（SHOW番号）

| SHOW | パーツ | 色 | 個数 | STL |
|---|---|---|---|---|
| 1 | jacket_shell_v2 | 🟠橙 | 1 | `v2/orange/jacket_shell_v2_x1.stl` |
| 2 | bottom_plate_v2 | 🟠橙 | 1 | `v2/orange/bottom_plate_v2_x1.stl` |
| 3 | mid_deck | ⚪灰 | 1 | `v2/gray/mid_deck_x1.stl` |
| 4 | servo_bracket | ⚪灰 | **2**（左右共通） | `v2/gray/servo_bracket_x2.stl` |
| 5 | top_lid | 🟠橙 | 1 | `v2/orange/top_lid_x1.stl` |
| 6 | cam_bezel | 🔴赤 | 1 | `v2/red/cam_bezel_x1.stl` |
| 7 | foot_base_v2 | ⚪灰 | 1 | `v2/gray/foot_base_v2_x1.stl` |

すべて平置き・サポート不要（shell は v1 同様そのまま上向き）。

## ⚠️ SG90 十字ホーンの向き・クリアランス

```
       腕穴(x≈78, z127)          ← ロープ
          ↑ ↑                       │
     十字ホーン(半径≈16で旋回)  ─────┘
       ●軸(x=±58, z=126, 軸=前後Y)
     [SG90本体] ← 壁沿いクレードルに落とし込み
```

- **SG90機構**: 軸は本体端から**5.8mm寄り**（中央でない）。十字ホーンは軸まわり**半径≈16mm**で円盤状に掃引。
- **90°回して当てない工夫**: ホーン面をクレードル背面の**後ろ(y≈3)**へ → 十字はタワーの後ろで回り**タワー自身と不干渉**。掃引円は**外壁と4.7mm・デッキと5.0mm**クリア（`SHOW`計算で検証）。
- **使う範囲**: アーム1本を「**真上→内側**」でのみ使用（外側へ回すと壁に当たる）。引き量はホーン15mmで120°≈22mm。
- **向き**: **軸端を外=腕穴側**に向けて挿入（左右で逆）。本体は内側へ伸び壁と干渉しない。内側タブ(x=±38)は掃引円の外なのでM2ボスを置ける。
- 実測寸法: 本体22.7×12.1・軸端から5.8mm・タブピッチ28.6・ホーン穴〜14mm。ポケット余裕±0.5mm/側。

## 📷 胸カメラ選定（調査 2026-07-27）

| 候補 | センサ | FOV | マイク | 基板/穴ピッチ | 判定 |
|---|---|---|---|---|---|
| **Arducam IMX291 UVC** ([Amazon.co.jp](https://www.amazon.co.jp/dp/B07ZRJDTBQ) / [公式](https://www.arducam.com/arducam-1080p-low-light-wdr-usb-camera-module-for-computer-2mp-1-2-8-cmos-imx291-100-degree-wide-angle-mini-uvc-spy-webcam-board-with-microph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)) | IMX291 2MP 低照度 | 100° | **あり** | 38×38 / **28×28**(設計値と一致) | ◎ **本命** |
| ELP-USBFHD06H ([仕様](http://www.webcamerausb.com/elp-100-degree-no-distortion-hd-camera-module-new-sony-imx323-color-sensor-free-driver-2mp-low-light-camera-usb-h264-1080p-30fps-wide-ang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) / [ELPストア](https://www.amazon.co.jp/stores/ELPUSBCamera/page/846B13E0-1C67-4A1A-8517-F14BB451E344)) | IMX323 2MP | ~100°(M12交換可) | あり | 38×38 / 図面非公開 | ○ 次点 |
| 汎用 OV2710 board | OV2710 2MP | 表記バラバラ | 物による | 32×32/38×38 非統一 | △ 安いがガチャ |
| C270 基板移植（現有） | 実績あり | **60°(狭い)** | あり | 細長基板・要実測 | ○ ¥0 暫定。追跡には狭い |
| MIPI CSI (OV5647等) | 5-8MP | 77-160° | **なし** | 25×24 | △ マイク別途・OpenCV運用が面倒 |

**推奨: Arducam IMX291 100° マイク付き** — UVCそのまま `/dev/video0`、C270 のマイク役も置換、
穴ピッチ28×28が `CAM_PITCH=28` と一致。購入までは C270 で胴内テスト可（レンズ窓φ12に寄せる）。

## ケーブルルーティング（下出し）

```
RDK X5 (ベイ内・ポートは背面ハッチ向き)
 ├─ 電源USB-C ← モバイルバッテリー(背面トレイ) … 胴内で完結
 ├─ 通信TypeC ──┐
 ├─ カメラUSB(胸ポケットへ上る)               │
 └─ ESP32-S3 USB(デッキへ上る)               │
         底板の窓(56×24) ↓ フットベース窓 ↓ 裏面排線溝 → 背面へ
```

- 外に出るのは**通信TypeC（+バッテリー充電時のケーブル）**。残りは胴内で上へ戻る。
- フットベース裏の**排線溝（幅26×深5）**でベタ置きでも背面へ逃げる。

## 組立手順

1. 底板に脚ボス→（任意）フットベースと M3×4 共締め or 両面テープ
2. RDK X5 ケースを裾からレールへ、バッテリーを背面トレイへ
3. SG90 を左右のコの字タワーへ上から落とし込み（**軸側の端を外側=腕穴側へ**）→ 内側タブを前面から M2×1
4. デッキを 4隅ボスに M3×4。ブレッドボード（ESP32-S3 載せたまま）を枠へ
5. ロープを 腕穴→ホーン先端（真上=静止位置、先端が穴の高さ）に結ぶ（ホーン真上で腕が自然に垂れる張り。引き=内側へ回す）
6. カメラ基板を胸ボス M2×4、ベゼルを外から。スピーカーは座リングに落として結束
7. リッドを天面レベートへ、襟→頭。**頭ごと持ち上げれば上から出し入れ可**

## プレビュー

| | |
|---|---|
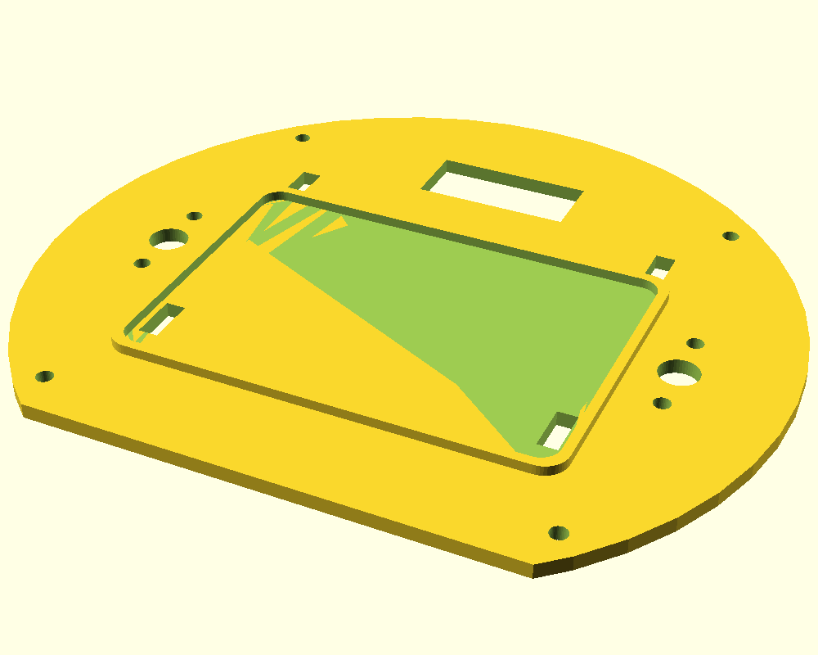
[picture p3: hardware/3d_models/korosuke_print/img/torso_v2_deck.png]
deck
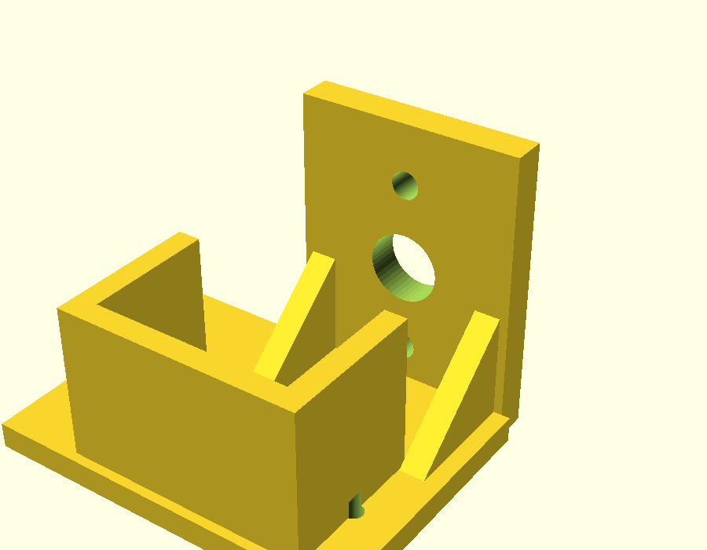
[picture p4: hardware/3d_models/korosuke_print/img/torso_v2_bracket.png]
bracket
|  |  |
| 中段デッキ（ブレッドボード枠・ロープ穴） | SG90 Lブラケット（窓23.1×12.5・穴ピッチ28.6） |
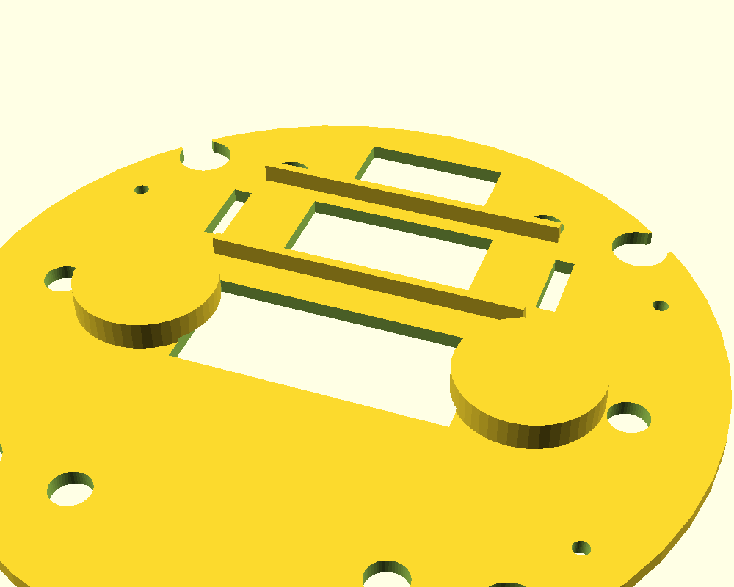
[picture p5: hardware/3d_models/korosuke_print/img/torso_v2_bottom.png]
bottom
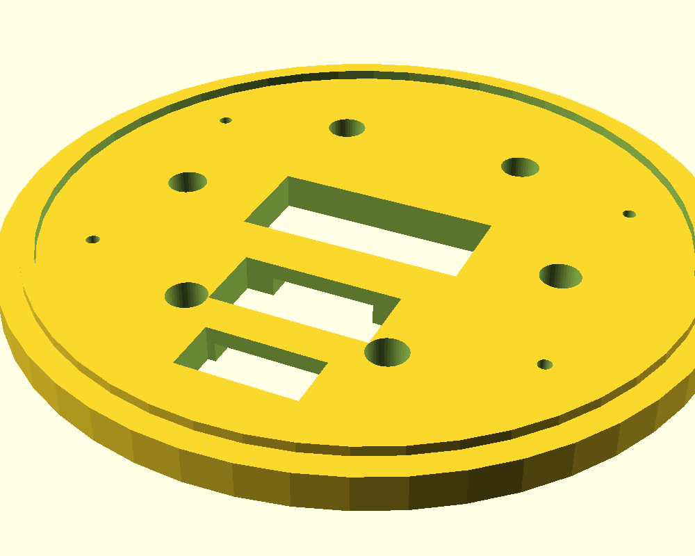
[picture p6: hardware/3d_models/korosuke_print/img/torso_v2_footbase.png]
footbase
|  |  |
| 底板（RDK窓・バッテリー窓・ベルクロ） | フットベース（同位置窓＋裏面排線溝） |

*未検証: 実機印刷はまだ。特に「バッテリー実寸（`PB_W/PB_T`）」「カメラ基板の実穴ピッチ」「フットベース土手径」は現物合わせで要確認。*

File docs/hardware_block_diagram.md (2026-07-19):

# Korosuke — ハードウェア ブロック図

> **この文書の性格:** 既存の設計文書には「論理データフロー図」しか無く、**電装の結線・電源・実装レイアウトを示す図が存在しなかった**ため、
> **現物ソース（`.scad` / firmware / ros2_ws）から逆算して起こしたもの**です。
> 記載は全て `file:line` で裏付けています。**推測は「推定」と明記**し、ソースに無いものは **UNDOCUMENTED** と書いています。
>
> 作成: 2026-07-17 / 対象リビジョン: `main` (c599c68)

## 凡例

| 表記 | 意味 |
|---|---|
| **実線** | ソースで実装・機構を確認済み。**現物に存在する** |
| **破線 / ⚠️** | ドキュメントには書かれているが、**実装または機構が存在しない** |
| **UNDOCUMENTED** | どこにも記載が無く、引き継ぐ人が決める必要がある |

---

## 1. 全体ブロック図

```mermaid
flowchart TB
  subgraph HEAD["🟡 頭部 — head_front + head_back（φ175 つぶし球）"]
    S3["<b>ESP32-S3 N16R8</b><br/>目コプロセッサ<br/>後頭部トレイに搭載"]
    LCD_L["GC9A01<br/>240x240 SPI<br/><b>左目</b> CS=GPIO10"]
    LCD_R["GC9A01<br/>240x240 SPI<br/><b>右目</b> CS=GPIO14"]
    NOSECAM["鼻カメラ穴 φ7.5<br/><i>USBカメラ想定・任意</i>"]
    S3 -->|"SPI2 @40MHz 共有バス<br/>SCK=12 / MOSI=11<br/>DC=9 / RST=8"| LCD_L
    S3 --> LCD_R
  end

  subgraph TORSO["🟠 胴体 — jacket_shell（φ158→165 × H165）"]
    RDK["<b>RDK X5 8GB</b> — 認知コア<br/>10 TOPS BPU / ROS 2 / Ubuntu 22.04<br/>ケース 91.4×62.4×27.1 を裾から縦挿入"]
    FAN["40mm ファン 5V<br/>40pinヘッダ給電<br/>66°C→49°C 実測"]
    CAM["USB UVC カメラ<br/>Stage1で実証済<br/>YOLO11n 8.3 FPS"]
    CHEST["ELP USB3D1080P02<br/>胸ステレオカメラ 任意<br/>⚠️ 胴に開口が無い"]
    AUDIO["INMP441 mic<br/>MAX98357A amp + SPK<br/>⚠️ 接続先 UNDOCUMENTED"]
    RDK --- FAN
    CAM -->|USB| RDK
    CHEST -.->|USB| RDK
    AUDIO -.->|"I2S?"| RDK
  end

  PWR["🔌 電源<br/><b>UNDOCUMENTED</b><br/>「LiPo 3S/4S + DC-DC + ACアダプタ」<br/>と1行あるのみ／MVPはベンチ電源"]

  RDK <==>|"<b>USB CDC</b> /dev/ttyACM*<br/>115200bps <b>ASCIIテキスト行</b><br/>emo / gaze / blink / idle"| S3
  PWR -.->|"5V?"| RDK
  PWR -.->|"?"| S3

  subgraph GHOST["⚠️ 設計文書にあるが、現物に存在しないもの"]
    UP["ESP32 上半身<br/>PCA9685 @0x40<br/>口2軸/首2軸/腕4軸"]
    LO["ESP32 下半身<br/>PCA9685 @0x41<br/>脚8軸 + BNO055"]
    QDD["SteadyWin GIM8108-36<br/>QDD ×8（CAN）<br/>⚠️ junk, unverified"]
  end

  RDK -.->|"UART 0xAA..0x55<br/>※ブリッジ未実装"| UP
  UP -.-> LO
  LO -.->|"CAN<br/>※実装0件"| QDD

  classDef real fill:#2d6a4f,stroke:#95d5b2,color:#fff
  classDef ghost fill:#4a1c1c,stroke:#e06c75,color:#fff,stroke-dasharray: 5 5
  classDef unk fill:#4a3c1c,stroke:#e5c07b,color:#fff,stroke-dasharray: 3 3
  class S3,LCD_L,LCD_R,RDK,FAN,CAM real
  class UP,LO,QDD,CHEST ghost
  class PWR,AUDIO,NOSECAM unk
```

---

## 1.5 実機検証結果（2026-07-18）

**目サブシステムはエンドツーエンドで動作確認済み**: リポジトリのソースをビルド → ESP32-S3へ書き込み →
2× GC9A01にアイドルアニメ表示 → ホストから `ping`→`pong` / `emo happy` / `gaze` / `blink` が全て機能。
配線（SPI共有バス+CS分離、3.3V給電）は第3章の表の通りで正しいことを実機で確認した。

> ⚠️ **Windows運用上の罠(実測)**: ESP32-S3の**ネイティブUSBポート**(VID_303A&PID_1001)は、
> Windowsの標準シリアルAPIで開くと**チップがDOWNLOADモードにリセットされる**(rst:0x15, boot:0x0 を確認)。
> Windowsからのモニタ/コマンドは**CH343側USB-C**(VID_1A86)を使うこと。ファームはUART0(CH343)からも
> 診断出力とコマンド入力を受ける(main.cppのSerial0)。
> ※RDK X5(Linux)からの接続は`serial_bridge_node`が`/dev/ttyACM*`(ネイティブUSB)を掴む設計 —
> Linuxで同じ罠が出るかは**統合時に要確認**。出る場合はCH343側(`/dev/ttyUSB*`)に切替可能。

> 🔊 **音響系の検証(2026-07-19, 再判定済)**: スピーカー(ES8326→3.5mm→アンプ内蔵SP)**動作**。
> **カメラ内蔵マイクも生きている** — スピーカー電源ONの再テストでビープ/音声を音響的に捕捉
> (一時「故障」と誤診したが、原因はテスト中スピーカーの電源がOFFで音源が存在しなかったこと)。
> ES8326のcaptureは**再生のサイドトーンのみ**(物理マイク無し。エコーキャンセルの参照信号として利用価値あり)。
> 音量は`amixer -c duplexaudio sset 'DAC' <n>%`(plughw直叩きはPulseAudio素通り、デスクトップ音量無効)。
> ⚠️ ALSAカード番号は再起動で入れ替わる — デバイスは番号でなく**名前**(`plughw:Microphone,0` / `plughw:duplexaudio,0`)で指定すること。
> ⚠️ vosk小型jaモデルはノイズ入力から「えーっと」等を幻聴する — 無音時の認識結果は信用しない(VAD必須)。

> ✅ **RDK X5側も検証済(2026-07-18夕)**: SSH(`sunrise@192.168.128.10`) → BPU YOLO11nライブ**19.5 FPS** /
> USBカメラ(Sunplus FHD, マイク内蔵)で録音+vosk日本語STT動作 / ESP32-S3を**CH343側**でRDKに接続すると
> `/dev/ttyACM0`として見え、**Linuxではリセット罠は発生しない**(pyserial直開きでpong応答) /
> `serial_bridge`+`eye_demo`によるROS 2→目の8表情巡回をユーザー目視で確認(**M2達成**)。

> 📝 **ビルド環境の修理履歴(2026-07-18)**: このPCの`framework-arduinoespressif32`パッケージは
> esp32s3 SDKが丸ごと欠落する破損状態だった(platformio.iniの「ManifestError」注記の実体)。
> パッケージ再取得で解消。LovyanGFXは1.1.16に完全固定した(^指定だと1.2.xが入り既知構成から乖離)。

## 2. 実在する信号経路（実装確認済み）

| # | 経路 | 物理層 | プロトコル | 根拠 |
|---|---|---|---|---|
| 1 | RDK X5 → ESP32-S3 | **USB CDC**（`/dev/ttyUSB*` / `/dev/ttyACM*` を自動選択） | **ASCIIテキスト行** 115200bps | [serial_bridge_node.py:44](../ros2_ws/src/korosuke_nodes/korosuke_nodes/serial_bridge_node.py#L44), [:71](../ros2_ws/src/korosuke_nodes/korosuke_nodes/serial_bridge_node.py#L71) |
| 2 | ESP32-S3 → GC9A01 ×2 | SPI2_HOST @ 40MHz、**バス共有・CS分離** | LovyanGFX `Panel_GC9A01` | [corosuke_eyes/main.cpp:31-36](../firmware/corosuke_eyes/src/main.cpp#L31-L36), [:48-51](../firmware/corosuke_eyes/src/main.cpp#L48-L51) |
| 3 | カメラ → RDK X5 | USB (UVC) | V4L2 | [STAGE1.md](../STAGE1.md), [scripts/cam_yolo.py](../scripts/cam_yolo.py) |
| 4 | ファン → RDK X5 | 40pinヘッダ 5V | — | [stage2_design.md:121](stage2_design.md#L121) |

### 2.1 コマンド語彙（RDK X5 → 目）

`serial_bridge_node` が `/korosuke/eye_cmd` (`korosuke_msgs/EyeCmd`) を購読し、**差分のみ**を1行ずつ書き込みます（[serial_bridge_node.py:80-92](../ros2_ws/src/korosuke_nodes/korosuke_nodes/serial_bridge_node.py#L80-L92)）:

```
emo <neutral|happy|sad|angry|surprised|sleepy>
gaze <x> <y>            # -1.0 .. 1.0
blink
wink <l|r>
idle <on|off>
ping                    -> "pong"
```

---

## 3. ESP32-S3 ピンアサイン（実装済み・唯一の正）

[firmware/corosuke_eyes/src/main.cpp:31-38](../firmware/corosuke_eyes/src/main.cpp#L31-L38) が唯一の正しいピン定義です。
**`firmware/common/config.h` は参照しないでください**（第6章参照）。

| 信号 | GPIO | 接続先 | 備考 |
|---|---|---|---|
| SCK | **12** | 両目共有 | SPI2_HOST, 40MHz |
| MOSI | **11** | 両目共有 | MISO は未使用 (-1) |
| DC | **9** | 両目共有 | |
| RST | **8** | 両目共有（物理結線） | **左目のみが駆動**。右目は `pin_rst=-1` |
| CS 左 | **10** | 左目のみ | |
| CS 右 | **14** | 右目のみ | |
| UART1 RX | 18 | ← RDK X5 TX | **実装済みだが現在未使用**（ブリッジはUSB経由） |
| UART1 TX | 17 | → RDK X5 RX | 同上 |

> ⚠️ **ハード上の注意（ファームのコメントに明記あり）:**
> GC9A01モジュール（M128-240240-RGB-7-V1.0）の **CSはプルダウン＝常時選択**。
> 2枚を1バスに繋ぐ場合、**両方のCSをGPIOで駆動しないと描画が衝突します**。
> このファームはそれを行っています（[main.cpp:13-14](../firmware/corosuke_eyes/src/main.cpp#L13-L14)）。

---

## 4. 実装レイアウト（どこに何が載るか）

```mermaid
flowchart TB
  subgraph H["頭部（内部）"]
    direction TB
    T["ESP32-S3 トレイ<br/>棚2枚 156×46×3<br/>z=-36 と z=-2（隙間31mm）<br/>⚠️ 基板の保持方法 UNDOCUMENTED"]
    P["GC9A01 ポケット φ37.6 × 2<br/>顔の<b>内側から</b>挿入<br/>表示窓 φ33（貫通）<br/>軸は球面法線 ±20°外向き"]
  end
  N["首穴 φ46<br/>頭側は y=+20 オフセット<br/>胴側は中心 → <b>20mmズレて対向</b>"]
  subgraph B["胴体（内部）"]
    direction TB
    BAY["RDK X5 ベイ<br/>縦レール（z=0..100）<br/>ケース遊び CASE_CLR=1.0<br/><b>裾から挿入</b>"]
    HATCH["背面ハッチ 70×100<br/>→ back_panel 69×99 で塞ぐ<br/>（クリアランス1mm・摩擦のみ）"]
  end
  BP["底板 bottom_plate<br/>φ151.4 を裾に圧入<br/>ケーブル穴 φ24<br/>脚ボス φ29 × 2"]
  H --> N --> B --> BP
```

| 部位 | 寸法 | 根拠 |
|---|---|---|
| ESP32-S3 トレイ | 棚2枚 `156×46×3`、z=`-36`/`-2`（**隙間31mm**） | [korosuke_print.scad:138-144](../hardware/3d_models/korosuke_print/korosuke_print.scad#L138-L144) |
| GC9A01 ポケット | φ**37.6** × 深さ（底=中心面-3.4）、窓φ**33** | [:65-70](../hardware/3d_models/korosuke_print/korosuke_print.scad#L65-L70), [:99-108](../hardware/3d_models/korosuke_print/korosuke_print.scad#L99-L108) |
| 首穴（頭側） | φ**46**、`translate([0,20,...])` = **y+20オフセット** | [:127](../hardware/3d_models/korosuke_print/korosuke_print.scad#L127) |
| 首穴（胴側） | φ**46**、中心 | [:195](../hardware/3d_models/korosuke_print/korosuke_print.scad#L195) |
| RDK X5 ベイ | レール間 = `CASE_D(62.4) + CLR(1.0)`、高さ100 vs ケース91.4 | [:73-74](../hardware/3d_models/korosuke_print/korosuke_print.scad#L73-L74), [:197-206](../hardware/3d_models/korosuke_print/korosuke_print.scad#L197-L206) |
| 背面ハッチ | 開口 70×100 / 蓋 69×99 | [:209](../hardware/3d_models/korosuke_print/korosuke_print.scad#L209), [:221](../hardware/3d_models/korosuke_print/korosuke_print.scad#L221) |
| ケーブル穴（底板） | φ24 | [:232](../hardware/3d_models/korosuke_print/korosuke_print.scad#L232) |
| スピーカーグリル | φ4 × 15穴（前面下部） | [:211-212](../hardware/3d_models/korosuke_print/korosuke_print.scad#L211-L212) |

---

## 5. 電源系統 — **未設計**

**リポジトリ全体に電源設計は存在しません。** 記載は以下の2箇所のみ:

- [stage2_design.md:140](stage2_design.md#L140) — `Power | LiPo 3S/4S + DC-DC + AC adapter | — | ✅ in stock`
- [stage2_design.md:184](stage2_design.md#L184) — R7: `separate LiPo rail + DC-DC per [inventory.md]; MVP runs on bench PSU`
  → **参照先の `docs/inventory.md` は存在しません**（`docs/bom.md` も同様）

### 推定される最小構成（※ソース上の断片からの推定・要検証）

現在の実装（ブリッジがUSBを掴む）から素直に読むと、MVPの電源ツリーはこうなるはずです:

```mermaid
flowchart LR
  PSU["ベンチ電源 / ACアダプタ<br/>5V"] --> RDK["RDK X5"]
  RDK -->|"USB<br/>バスパワー"| S3["ESP32-S3"]
  RDK -->|"40pin 5V"| FAN["40mm ファン"]
  RDK -->|"USB<br/>バスパワー"| CAM["USBカメラ"]
  S3 -->|"3.3V<br/>オンボードレギュレータ"| LCD["GC9A01 ×2<br/>バックライト込 推定80mA"]
```

つまり **RDK X5に5Vを1本入れれば全系統が動く**可能性が高く、これがMVPの最短経路です。
ただし**これはソースに書かれていない推定**であり、RDK X5のUSBポートの給電能力と実測消費で確認が必要です。

---

## 6. ドキュメントとの相違（**重要**）

引き継ぎ時に**そのまま信じると詰まる**箇所です。

| # | ドキュメントの記述 | 実際 | 影響 |
|---|---|---|---|
| **D1** | [stage2_design.md:100-102](stage2_design.md#L100-L102) —「`protocol.h` (0xAA…0x55) をワイヤフォーマットとして**維持**し、`serial_bridge_node` がROS2メッセージをそれにシリアライズする」 | **嘘。** `serial_bridge_node` は **ASCIIテキスト行**を書いている（`emo happy\n`）。目ファームは `protocol.h` を **include すらしていない** | 0xAA..0x55 を前提に実装すると**全く通信できない** |
| **D2** | [config.h](../firmware/common/config.h) — 目H/V・まぶた・口・首・腕・脚の20軸以上のサーボ定義 | **旧アーキテクチャの化石。** 現行の印刷設計にこれらの機構は**1つも存在しない**。ピンも目ファームと無関係 | ピン表として参照すると**全て間違う** |
| **D3** | [config.h:115,119](../firmware/common/config.h#L115-L119) | `I2S_DIN_PIN 9` と `MIC_SD_PIN 9` が**衝突**（別バス定義なのに9番共有） | 音声を2バス構成で組むと破綻 |
| **D4** | [PRINT_GUIDE.md:47](../hardware/3d_models/korosuke_print/PRINT_GUIDE.md#L47) / korosuke_print/README.md —「前後割り**+ピン4**」 | **ピンは存在しない。** `locpin()`/`locpin_hole()` は[:89-90](../hardware/3d_models/korosuke_print/korosuke_print.scad#L89-L90)で**定義のみ・呼び出し0回**。合わせはリップ(`LIP_H=6`)だけ | 頭の位置決めを別途考える必要 |
| **D5** | [PRINT_GUIDE.md:56](../hardware/3d_models/korosuke_print/PRINT_GUIDE.md#L56) —「胴に外から当ててM2×4でネジ止め」 | **胴に穴が無い。** `chest_cut()` は[chest_cam.scad:68-71](../hardware/3d_models/stereo_cam/chest_cam.scad#L68-L71)に「jacket統合用」として定義されているが、`jacket_shell` に**適用されていない**。2ファイルは `use<>` で連携すらしていない | 胸カメラは**取付不可**（統合作業が必要） |
| **D6** | [README.md:80](../README.md#L80) / [stage2_design.md:128](stage2_design.md#L128) が `docs/bom.md` `docs/inventory.md` を参照 | **両方存在しない** | 電源・部品の参照先が消失 |
| **D7** | [korosuke_print/README.md:22](../hardware/3d_models/korosuke_print/README.md#L22) — 腕=紺青A/B交互リング、頭/胴=橙 | **古い。** 現行は `PALETTE="anime"`（[:36](../hardware/3d_models/korosuke_print/korosuke_print.scad#L36)）で頭=淡黄/胴=橙、腕=**水色単色×16**。`preview_iso.png` も旧配色のまま | 配色を間違えて印刷する |
| **D8** | [README.md:35](../README.md#L35) — 2軸マウスのリップシンク / 首の追従 (G2) | **機構が存在しない。** 口は固定スリット（[:118-119](../hardware/3d_models/korosuke_print/korosuke_print.scad#L118-L119)）、首サーボ無し、頭と胴を留める機構すら無い | リップシンク・首追従は**未設計** |
| **D9** | [README.md:35](../README.md#L35) 二足歩行 / [stage2_design.md:139](stage2_design.md#L139) QDD×8 (CAN) | **脚の設計が3つ食い違う。** ①現物=φ36中空パイプ・関節0 ②firmware=PWMサーボ9軸 ③BOM=CAN QDD×8。CANの実装は**リポジトリ全体で0件**（TWAI/MCP2515/トランシーバ全て無し）。GIM8108は推定φ90でLEG_D=36に**物理的に入らない** | 脚は**スコープ外**として扱うのが妥当 |

---

## 7. 現物に存在する基板の全リスト

| 基板 | 搭載位置 | 接続 | 状態 |
|---|---|---|---|
| **RDK X5 8GB** | 胴内・縦置きベイ（裾から挿入） | 5V入力 / USB×N / 40pin | ✅ 実機動作（Stage1） |
| **ESP32-S3 N16R8** | 後頭部トレイ | USB ← RDK X5 | ✅ ファーム実装済 |
| **GC9A01 ×2** | 顔の内側ポケット φ37.6 | SPI ← ESP32-S3 | ✅ ファーム実装済 |
| **USBカメラ** | 鼻穴 φ7.5 or 胸（※胸は取付不可） | USB ← RDK X5 | ✅ Stage1実証 |
| **40mmファン** | RDK X5ケース蓋 | 40pin 5V | ✅ 実測 −17°C |
| INMP441 / MAX98357A | UNDOCUMENTED | UNDOCUMENTED | ⚠️ 接続先未設計 |

**退役扱い（現物と対応しない）:** `firmware/corosuke_main`（[stage2_design.md:194](stage2_design.md#L194) が明示的に retire）、`firmware/corosuke_upper`、`firmware/corosuke_lower`、`firmware/common/config.h`、`firmware/common/protocol.h`

---

## 8. 引き継ぎ者が決める必要があるもの

1. **電源** — 5V単一で足りるか。バッテリ運用するか、ベンチ電源のままか
2. **ESP32-S3の保持方法** — トレイは隙間31mmの棚2枚のみ。ネジ/タイラップ/両面テープのいずれか
3. **頭と胴の固定** — 現状、機構が無い（頭は載っているだけ）
4. **音声の接続先** — RDK X5のI2Sか、ESP32-S3に相乗りさせるか
5. **胸カメラを使うか** — 使うなら `jacket_shell` に `chest_cut()` を統合する作業が必要
6. **口/首/腕/脚を動かすか** — 動かすなら機構から新規設計（現行は全て静的）

---

*この文書は現物ソースから機械的に起こしたものです。矛盾を見つけたら、`.scad` / firmware を正とし、この文書を修正してください。*

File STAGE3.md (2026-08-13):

# Project Korosuke — Stage 3 (Launch): Fully On-Device Interactive Robot

<p>
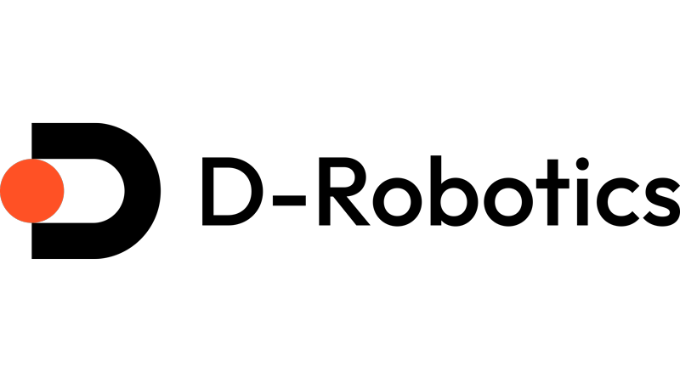
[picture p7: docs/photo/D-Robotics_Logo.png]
D-Robotics

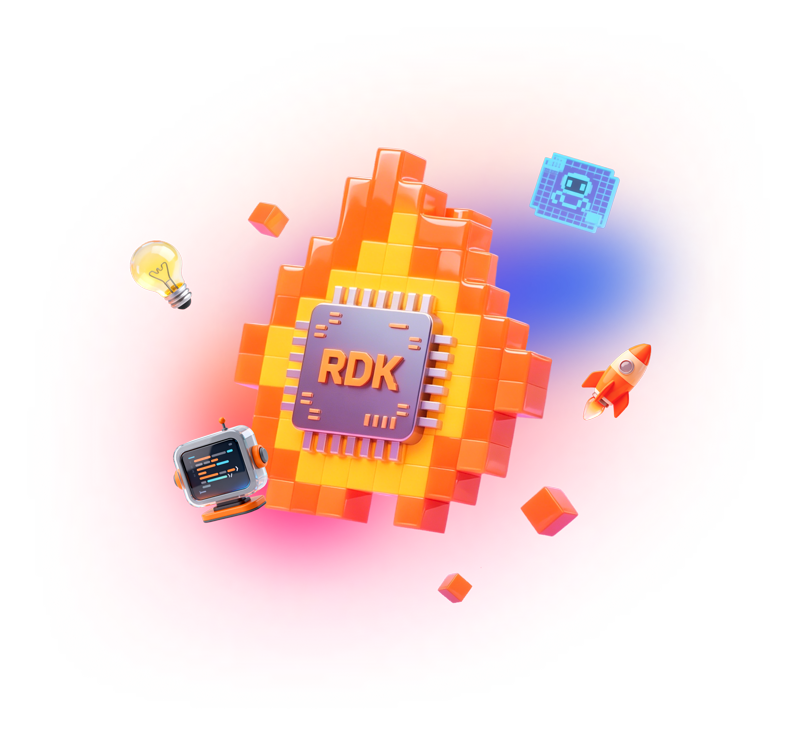
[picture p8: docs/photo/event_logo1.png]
Robotics Dream Keeper Challenge

</p>

D-Robotics **Robotics Dream Keeper Challenge** — Stage 3 showcase.
Korosuke (コロ助), the karakuri-robot from *Kiteretsu Daihyakka*, rebuilt as a ~46 cm
desktop animatronic whose brain is an **RDK X5** (10 TOPS BPU "Bayes-e", 8× Cortex-A55,
Ubuntu 22.04). A fan-made, non-commercial tribute.

Korosuke revision 0.1 — fully assembled, smiling

> **Headline:** Korosuke **wakes up and greets you, sees you and follows you with its eyes, listens,
> thinks, talks back, smiles, ponders, reacts to gestures, waves
> its arms, and shuts itself down safely — 100 % on-device. No cloud. No dev PC at
> runtime.** Vision, speech-to-text, LLM dialogue, text-to-speech, expression, gesture
> and actuation all run on a single RDK X5 + an ESP32-S3 eye/arm co-MCU.

🎥 **[▶ Watch the 10-second on-device conversation demo →](docs/photo/korosuke_demo_10s.mp4)**

---

## 1. What Korosuke does (the integrated experience)

Power it on and, unattended:

0. **Wakes up** — on boot it auto-starts, self-checks its audio, blinks its eyes into a
   smile and says *"おはようナリ！コロ助、起きたナリ！"* while waving.
1. **Sees you** — BPU YOLO11-pose finds the largest person + 17-point skeleton.
2. **Looks at you** — the round eyes (2× GC9A01) track your position.
3. **Greets you** — a "…ナリ" greeting in a high childlike voice + waves both arms.
4. **Emotes** — smile / sad / angry / surprised / sleepy on the round displays.
5. **Reacts to gestures** — both hands up → *"バンザイ！"* + raises both arms; one hand
   up → *"はーい、ナリ！"*; one-hand wave → waves back with that arm.
6. **Talks with you** — your speech is transcribed on-device (sherpa-onnx JP); while the
   **on-device LLM** (TinySwallow-1.5B) thinks, the eyes show a **"考え中" pondering
   animation**; the reply is spoken via on-device TTS (Open JTalk) in Korosuke's
   "ワガハイ…ナリ" persona, and the eyes break into a smile.
7. **Misses you** — when you leave frame it droops, says a farewell, then settles back
   to a calm awake face.
8. **Sleeps safely** — a physical button runs a graceful shutdown: sleepy eyes →
   *"おやすみナリ…また会おうナリ！"* → **✕✕ "power-off-OK" eyes** that stay lit after the
   OS halts, so you know when it's safe to cut power.

A **web dashboard** (`http://<board-ip>:8080`, tabbed **Monitor / Settings**) shows the
live camera + skeleton, mic level, recognition state and speech — and lets you tune every
parameter (volume, mic gain, voice pitch, thresholds, reaction toggles, eyes, arms, and a
**one-click audio self-test**) live from any PC on the LAN.

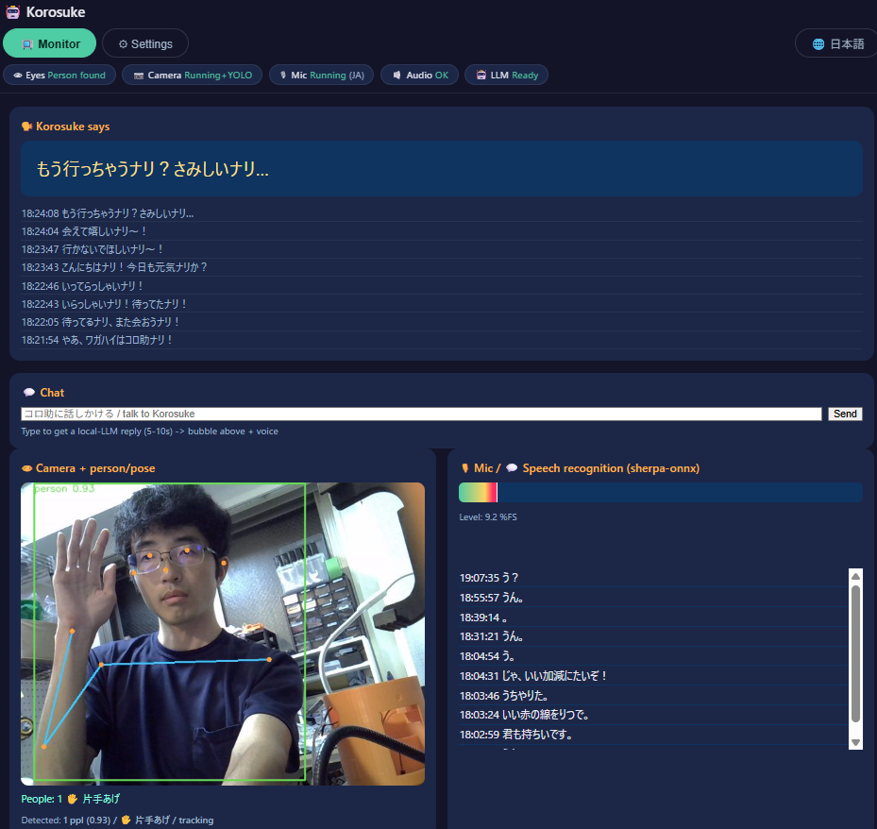
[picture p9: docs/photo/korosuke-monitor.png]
Korosuke web dashboard — live camera + skeleton, recognition state and conversation log


## 2. Stage-3 technical achievements (all measured on the real board)

| Capability | Implementation | On-device measurement |
|---|---|---|
| Vision (person + pose) | BPU YOLO11n-pose (Bayes-e `.bin`) | live camera ~**19.5 FPS** |
| Speech-to-text | **sherpa-onnx SenseVoice** (multilingual JP/EN/…, int8) + Silero VAD | real-time on CPU |
| **On-device LLM dialogue** | **llama.cpp + TinySwallow-1.5B** *(Qwen2.5-1.5B-based)* Q5 (CPU) | load 24 s, **1.5–3.3 tok/s**, reply 5–10 s |
| Text-to-speech | **Open JTalk** (JP) / **espeak-ng** (EN), pitched childlike voice | dynamic, any text, instant |
| **Audio out (miniaturized)** | **MAX98357A** I2S Class-D amp on 40-pin **i2s1** + φ50 8Ω speaker | custom-built card, DSP-tuned |
| Expression | 2× GC9A01 on ESP32-S3 (LovyanGFX): 8 states incl. smile / pondering / ✕✕ | ≥30 FPS render |
| Gesture recognition | skeleton (wrist-vs-shoulder): both/one raise + wave | in the pose loop, no extra model |
| Arm actuation | 2× SG90 rope-pull bellows arms on ESP32-S3 LEDC PWM | GPIO4/5, auto-detach to save current |
| Safe power | GPIO shutdown button + boot auto-start (systemd) | goodnight voice + ✕✕-eyes signal |
| Maintenance net | eth0 **static 192.168.0.200** + usb0 gadget lifeline | auto-assigned on boot |

**Whole-stack thermal benchmark** (camera + pose + STT + LLM + TTS + eyes + arms all at
once, LLM pinning ~**600 % CPU**): CPU **≈50 °C** / BPU **≈50 °C** / DDR **≈51 °C**
(target < 60 °C ✅, no fan throttling), RAM ~2.2 GiB / 6.9 GiB used. The full experience
fits with headroom on one 8 GB board.

## 3. Hardware, miniaturized and packed into the body

The Stage-3 build moved the whole brain **inside the 3-D-printed body** (OpenSCAD,
color-split printing). Two size problems were solved this stage:

- **Speaker → MAX98357A.** The oversized 5 cm enclosed speakers were replaced by a small
  **φ50 mm 8 Ω driver** driven by a **MAX98357A I2S digital amp** off the RDK X5 40-pin
  I2S1. Because the RDK kernel ships **no** MAX98357A codec driver (and no in-tree dummy
  codec), we **built `snd-soc-max98357a` out-of-tree** against the on-board
  `hobot-kernel-headers`, authored a **device-tree overlay** (`simple-audio-card`,
  `dw_i2s1` ↔ `maxim,max98357a`), and made it auto-load. See
  [docs/rdk_x5_40pin_i2s_max98357a.md](docs/rdk_x5_40pin_i2s_max98357a.md).
- **Camera → bare UVC webcam** in the chest, behind the nose/chest port (see the lens in
  the chest cut-out of the hero photo). It is auto-detected (USB-preference, so RDK
  internal video nodes are never mistaken for the camera) and its built-in mic feeds STT.

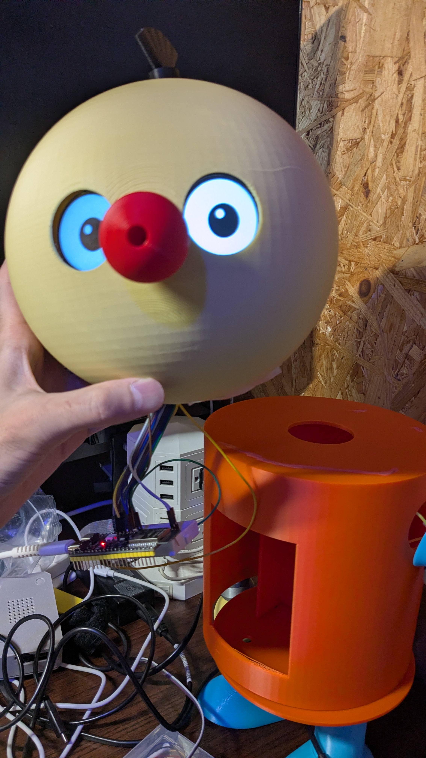
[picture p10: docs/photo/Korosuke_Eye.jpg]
Korosuke's head — 2× GC9A01 round eyes + red camera-nose, driven by the ESP32-S3 co-MCU


*The head carries the two round GC9A01 eye displays (here in the wide "awake" look) and
the camera-in-nose port; the ESP32-S3 co-MCU on the bench drives the eyes and arms. The
orange body hides the RDK X5 + fan + MAX98357A amp + φ50 speaker.*

<p>
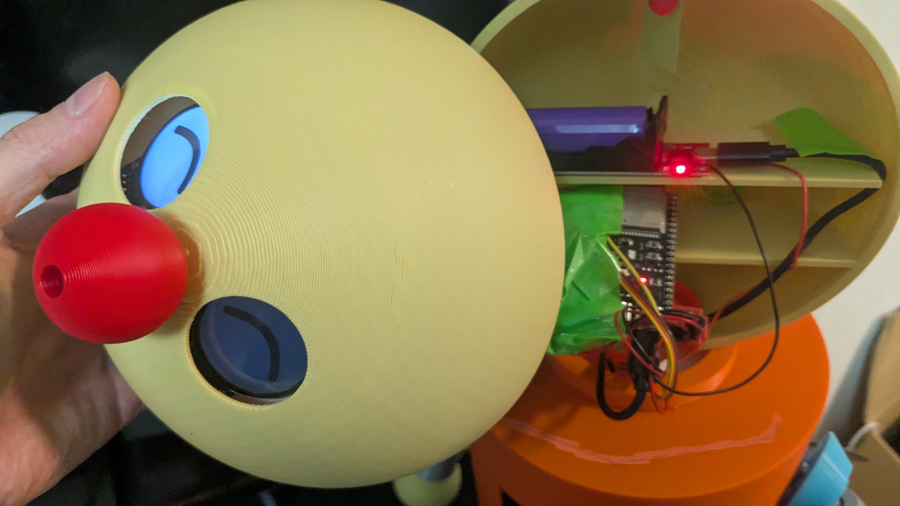
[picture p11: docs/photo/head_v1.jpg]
Inside the head — eye displays behind the face, ESP32-S3 co-MCU on its tray

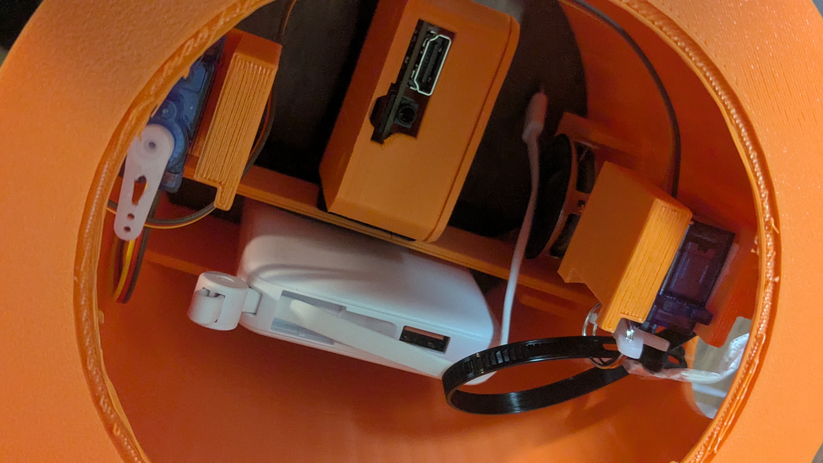
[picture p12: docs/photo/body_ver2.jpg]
Inside the torso — RDK X5, power bank, SG90 arm servos and speaker packed in

</p>

*As-built internals: **inside the head** (eye displays behind the face, ESP32-S3 co-MCU on its tray) and
**inside the torso** (RDK X5 case, power bank, 2× SG90 rope-pull servos and the φ50 speaker — everything packed in).*

🎥 **Watch:** [**10-second on-device conversation demo**](docs/photo/korosuke_demo_10s.mp4) ·
[rope-pull arm driven by the SG90 servo](docs/photo/arm_rope_pull.mp4)

### How it all wires together

```mermaid
flowchart LR
  %% All parts are boxes. Colour = category. Pin numbers are on the wires (edge labels).
  PB["🔋 Mobile battery<br/>(power bank) 5V/3A"]:::power
  LIPO["🔋 LiPo<br/>(for servos)"]:::power
  RDK["🧠 RDK X5 (10 TOPS)<br/>(brain — everything on-device)"]:::main
  ESP["ESP32-S3<br/>(eyes/arms MCU)"]:::compute
  AMP["MAX98357A<br/>I2S amp (GAIN=9dB)"]:::module
  EYES["2× GC9A01<br/>round LCD (eyes)"]:::module
  CAM["📷 Camera C270<br/>(built-in mic)"]:::periph
  BTN["⏻ Shutdown button"]:::periph
  SPK["🔊 φ50 speaker"]:::periph
  SRV["💪 2× SG90<br/>servos (arms)"]:::periph

  PB   -->|"USB-C 5V/3A"| RDK
  CAM  -->|"USB (video + audio)"| RDK
  BTN  -->|"pin18(GPIO24) / pin20(GND)"| RDK
  RDK  -->|"USB (power + data · ttyACM0)"| ESP
  RDK  -->|"5V:pin2/4 · GND:pin6<br/>BCLK:pin12 · LRC:pin35 · DIN:pin40"| AMP
  AMP  -->|"analog +/−"| SPK
  ESP  -->|"SPI: SCK12·MOSI11·DC9·RST8<br/>CS_L10·CS_R14 · 3V3·GND"| EYES
  ESP  -->|"PWM: GPIO4(L) / GPIO5(R)"| SRV
  LIPO -->|"LiPo voltage direct (no BEC)"| SRV
  LIPO -.->|"common GND ⚠ (required)"| ESP

  classDef power   fill:#f6b73f,color:#3a2a00,stroke:#c98a12,stroke-width:2px;
  classDef compute fill:#1f6feb,color:#fff,stroke:#58a6ff,stroke-width:2px;
  classDef module  fill:#8957e5,color:#fff,stroke:#bc8cff,stroke-width:2px;
  classDef periph  fill:#2da44e,color:#fff,stroke:#3fb950,stroke-width:2px;
  classDef main    fill:#1f6feb,color:#fff,stroke:#ffffff,stroke-width:4px,font-size:22px;
```

**Two power rails** (power bank → RDK X5 · LiPo → servos) with a **shared common ground**;
pin numbers are on the wires. Full connection table & notes: [docs/wiring.md](docs/wiring.md).

## 4. Engineering deep-dives (what made this hard, and how we proved it)

- **The BPU does vision; the CPU does language — and we proved the BPU *cannot* do the
  LLM on X5.** A multi-language, source-verified investigation
  ([docs/rdk_x5_bpu_llm.md](docs/rdk_x5_bpu_llm.md)) concludes: the RDK X5 Bayes-e BPU has
  **no official LLM toolchain** — the "large-model toolchain" is **RDK S100 (Nash)
  only**. Decisive evidence: D-Robotics' *own* X5 packages (`magicbox_qwen_llm`,
  `InternVL2_5-1B-GGUF-BPU`) run the language model on **llama.cpp/CPU**; the BPU only
  accelerates the vision (ViT) tower. So Korosuke's design — perception on the BPU,
  dialogue on the 8× A55 CPU — is the *correct* architecture for this board, not a
  limitation we failed to overcome.
- **"Loud but clean" on a tiny speaker.** We measured the small driver's clean ceiling at
  **≈ −6 dBFS** and built a playback DSP (high-pass to protect the cone + compressor +
  brick-wall limiter + peak-normalize to the ceiling) so the childlike voice is loud
  without the onset clipping we first heard. Output is a modest ~0.1–0.4 W — deliberately
  speaker-limited, not amp-limited.
- **Self-healing audio.** A cold-boot module load-order race can leave the I2S card in an
  un-openable state. A boot-time root service **and** a web **"🔈 audio self-test"**
  button verify the card and, if needed, re-bind it automatically.
- **Robust to hardware reality.** Debugged live: ESP32-S3 LEDC is **14-bit max** (16-bit
  silently emits no PWM); the eye's native-USB port resets on host open (use the CH343
  UART); servo release needs `ledcDetachPin`, not duty-0; a half-inserted USB power cable
  and a bad USB cable were diagnosed straight from `dmesg` (`Cannot enable. Maybe the USB
  cable is bad?`); camera/mic device names and indices are auto-detected so swapping the
  webcam "just works."

## 5. Architecture (no cloud)

**The BPU does perception; the CPU does language** — two parallel workloads, one board,
zero cloud. (GitHub renders the Mermaid diagram below.)

```mermaid
flowchart LR
    CAM([UVC Camera]):::s --> YOLO
    MIC([USB Mic]):::s --> STT
    BTN([Shutdown button]):::s --> BRAIN

    subgraph RDK["RDK X5 · fully on-device"]
      direction TB
      subgraph BPU["BPU (10 TOPS) — PERCEPTION"]
        YOLO["YOLO11n-pose (19.5 FPS)"]
      end
      subgraph CPU["CPU 8× A55 — LANGUAGE"]
        STT["STT: sherpa-onnx"]
        LLM["LLM: TinySwallow-1.5B"]
        TTS["TTS: Open JTalk"]
      end
      BRAIN{{"brain (korosuke-monitor)"}}
    end

    YOLO --> BRAIN
    STT --> BRAIN
    BRAIN --> LLM --> BRAIN
    BRAIN --> TTS --> AMP["MAX98357A amp"] --> SPK([φ50 speaker]):::o
    BRAIN -->|USB / UART| ESP32["ESP32-S3 (eyes + arms)"]:::m
    ESP32 --> EYES["2× GC9A01 eyes"]:::m
    ESP32 --> ARMS["2× SG90 arms"]:::m

    classDef s fill:#1f6feb,color:#fff,stroke:#58a6ff;
    classDef m fill:#8957e5,color:#fff,stroke:#bc8cff;
    classDef o fill:#2da44e,color:#fff,stroke:#3fb950;
```

The board brings up its own network — reachable at **eth0 static `192.168.0.200`** on the LAN,
**or `192.168.128.10` over the Type-C (USB-C) gadget link** to a PC — and every component is a
**systemd** service that auto-starts on power-on. **No dev PC at runtime.**

### 5.1 ROS 2 node / topic graph (as-built)

The same pipeline is also implemented as a **ROS 2 graph** — 6 nodes + 2 custom messages,
started with `ros2 launch korosuke_nodes korosuke.launch.py` (code: [`ros2_ws/`](ros2_ws/);
Stage-2 design: [PROPOSAL.md §2.2](PROPOSAL.md)):

```mermaid
flowchart LR
    ASR[/"user_text · String<br/>(from STT)"/]:::ext
    VIS(["vision_node"]):::n
    BRAIN(["brain_node"]):::n
    DIAG(["dialogue_node"]):::n
    VOICE(["voice_node"]):::n
    BRIDGE(["serial_bridge_node"]):::n
    ESP["ESP32-S3<br/>eyes + arms"]:::hw
    SPK["φ50 speaker"]:::hw

    VIS -->|"/korosuke/face_pose · FacePose"| BRAIN
    BRAIN -->|"/korosuke/greet · String"| DIAG
    ASR -->|"/korosuke/user_text · String"| DIAG
    DIAG -->|"/korosuke/say_text · String"| VOICE
    BRAIN -->|"/korosuke/eye_cmd · EyeCmd"| BRIDGE
    DIAG -->|"/korosuke/eye_cmd · EyeCmd"| BRIDGE
    BRIDGE -->|"UART frames"| ESP
    VOICE -->|"Open JTalk"| SPK

    classDef n fill:#8957e5,color:#fff,stroke:#bc8cff;
    classDef hw fill:#2da44e,color:#fff;
    classDef ext fill:#1f6feb,color:#fff;
```

**Two integrations of one on-device pipeline.** The ROS 2 graph above (custom messages
`FacePose` / `EyeCmd`, topic-based nodes) satisfies the challenge's ROS 2 requirement; its
`dialogue_node` / `voice_node` run the **same fully on-device stack as the monolith —
TinySwallow-1.5B via llama.cpp and Open JTalk (no cloud, no API keys)**. For the interactive
showcase we also ship a **single low-latency `korosuke-monitor` service** that fuses the same
stages in one process (adding the Web dashboard, audio DSP and the 8-state eyes).

> **Verification status (honest).** All live testing and the demo video use the **monolith**.
> In the ROS 2 graph, the `vision_node → brain_node → serial_bridge → eyes` path is
> **verified on hardware**; the full graph including `dialogue_node` / `voice_node` is
> **code-complete and reuses the monolith's proven on-device modules, but has not yet been
> run end-to-end on the board.** Listening (STT) is **not yet a ROS node** — `dialogue_node`
> consumes `/korosuke/user_text`, which the monolith's sherpa-onnx STT (or manual input)
> publishes; a dedicated `stt_node` is future work.

**Web control of the ROS graph.** Launch with `with_web:=true` to also start
`rosbridge_server` (WebSocket :9090); then open [`ros2_ws/.../web/console.html`](ros2_ws/src/korosuke_nodes/web/console.html)
in a browser and connect to `ws://<board-ip>:9090`. The page is **dependency-free** — it
speaks the rosbridge JSON protocol over a raw WebSocket (no roslibjs, no CDN, on-device
friendly) — and lets you talk to `/korosuke/user_text`, drive `/korosuke/eye_cmd`
(emotions incl. thinking/✕✕, gaze, blink), and watch `/korosuke/say_text` +
`/korosuke/face_pose` live. (The monolith keeps its own richer dashboard at `:8080`.)

## 6. Innovation highlights

- **A complete on-device conversational + expressive robot on a $140-class board** —
  ASR, a real LLM, TTS, 8-state emotion, gesture and actuation, zero cloud.
- **Bilingual, on the fly (日本語 / English)** — one switch flips the *whole* robot between
  Japanese and English: speech recognition (sherpa-onnx), the LLM's persona & replies
  (TinySwallow-1.5B), the voice (Open JTalk / espeak-ng) **and** the web dashboard — with
  **no cloud, no API keys**. The dashboard shows the live AI stack in use (LLM / persona /
  STT / TTS) so what's running is always transparent.
- **Aligned with D-Robotics' own reference voice stack** — the on-device pipeline mirrors
  D-Robotics' official RDK
  [voice-interaction guide](https://developer.d-robotics.cc/magicbox_doc/en/algorithm-development/voice-interaction):
  **SenseVoice** multilingual ASR (sherpa-onnx) + a **Qwen2.5-1.5B-family** LLM — we run the
  Japanese-tuned **TinySwallow-1.5B** (built on Qwen2.5-1.5B) on llama.cpp/CPU.
- **Character-faithful & alive**: pitched "ワガハイ…ナリ" voice; hand-tuned **smile** and a
  **"thinking" eye animation** during the LLM's think time so the wait feels intentional;
  a rope-pulled bellows arm matching the 3-D-printed center-bore.
- **Custom kernel work**: an out-of-tree ALSA codec driver + device-tree overlay to add a
  digital I2S amp the vendor kernel didn't support — turning a $2 amp into a body-fit speaker.
- **Ships like a product**: power-on-to-greeting auto-start, a physical safe-shutdown with
  a clear "safe to unplug" signal, a static maintenance IP, and a web self-test.

## 7. Build / BOM

📋 **Full itemized BOM (with rationale) is in the Stage-2 design → [PROPOSAL.md §3.1](PROPOSAL.md).**
To avoid duplication, this section lists only the **Stage-3 as-built hardware changes** vs. that plan:

| Change in Stage 3 | Part | Why / ref |
|---|---|---|
| **Speaker miniaturized** | MAX98357A I2S amp + φ50 mm 8 Ω driver (WYGD50D-8-03) | fit the body; needed a **custom out-of-tree kernel driver + DT overlay** — [build](docs/rdk_x5_40pin_i2s_max98357a.md) · [firmware/max98357a/](firmware/max98357a/) · [g109012](https://akizukidenshi.com/catalog/g/g109012/) |
| **Camera** | UVC USB webcam (Logitech C270), mic built-in | on-device vision + STT; auto-detected on replug |
| **Safe power** | GPIO shutdown button | graceful halt (goodnight voice → ✕✕ eyes) — [deploy/](deploy/) |
| Mic | uses the C270's built-in mic (INMP441 in the plan not needed) | one fewer part |

> Louder-speaker upgrade path (optional): a φ40 mm **4 Ω / 3 W** full-range
> ([DXYD40-22P-4A](https://akizukidenshi.com/catalog/g/g116025/)) in a small sealed baffle
> roughly doubles clean output (mind the DSP ceiling, §8).

**Wiring & diagnostics:** [hardware block diagram](docs/hardware_block_diagram.md) ·
[40-pin I2S / MAX98357A](docs/rdk_x5_40pin_i2s_max98357a.md) ·
[network / maintenance](docs/network_setup.md) ·
[power/USB brown-out](docs/power_usb_troubleshooting.md).

## 8. Known issues, limitations & failure recovery

| Area | Known limitation | Recovery / mitigation |
|---|---|---|
| **LLM latency** | on-device 1.5B on CPU → 5–10 s to reply (the BPU *cannot* accelerate LLM on X5) | "考え中" eye animation covers the wait; canned "…ナリ" fallbacks — see [BPU-LLM analysis](docs/rdk_x5_bpu_llm.md) |
| **Power / USB brown-out** | an inadequate USB-C cable/adapter → no green LED, USB peripherals drop, flaky network | 5 V/3 A+ certified supply + short thick cable; diagnose from `dmesg`; full guide → [power_usb_troubleshooting.md](docs/power_usb_troubleshooting.md) |
| **Audio-card cold-boot race** | module load-order can leave the I2S card un-openable | boot-time root service **+** web **"🔈 audio self-test"** auto-rebind |
| **Peripheral swap** | camera index / mic-card name can change on replug | auto-detected (USB-preference + name lookup) |
| **No RTC** | battery-less clock resets offline | fake-hwclock; NTP when online |
| **Bipedal gait** ✴️ | stretch only — the salvaged QDD motors are unreliable | MVP is seated/standing; decoupled from the critical path |

**Not implemented in this build (deferred, not claimed as done):**
- **2-axis mouth / lip-sync** — no mouth mechanism is fitted; all expression is via the eyes and voice. Lip-sync (proposed as G4) is deferred.
- **Bipedal "penguin" walking (QDD legs)** — stretch only; the salvaged QDD motors are unreliable, so the MVP is a seated/standing torso.
- **Back-mounted sword prop** — not built.
- **Neck servo (head turn)** — face tracking is **eyes-only**; no neck actuator is fitted.
- **Head touch / "petting" reaction** — the firmware has a touch path, but no working touch sensor is fitted in this build.

**Safe shutdown / soft E-STOP:** a GPIO button runs a graceful halt (goodnight voice → ✕✕
"power-off-OK" eyes that persist after the OS halts); the arm servos **auto-detach** (zero
torque) between moves and on a web "🪫 relax" command — documented safety limit.

## 9. Stage-3 requirement coverage (for reviewers)

| Requirement | Where |
|---|---|
| System architecture | §5 Mermaid + ROS 2 graph ([PROPOSAL.md §2.2](PROPOSAL.md), code [`ros2_ws/`](ros2_ws/)) |
| **BPU-accelerated model** (name + runtime) | **YOLO11n-pose on Bayes-e BPU, ~19.5 FPS** (§2, table below) |
| Continuous real-time detection | pose loop runs live (not single-frame) |
| Multi-task (2+ parallel workloads) | BPU vision **+** CPU STT/LLM/TTS concurrently; CPU/BPU load & thermal in §2 |
| Motor/actuator control + safety limits | 2× SG90 rope-pull arms, auto-detach; 14-bit LEDC (§4, §8) |
| Safe shutdown / E-STOP | GPIO button + ✕✕-eyes signal (§8) |
| Interface spec / calibration | [docs/rdk_x5_40pin_i2s_max98357a.md](docs/rdk_x5_40pin_i2s_max98357a.md), [docs/TESTING.md](docs/TESTING.md) |
| Known issues / failure recovery | §8 + docs/ |
| Reproducible build / Quick Start | §10 + repo `README.md` |
| **Demo video 3–7 min (YouTube)** | ✅ [youtu.be/NJwj6Iazd20](https://youtu.be/NJwj6Iazd20) |
| **LICENSE · community post · showcase PR** | ⚠️ **TODO** before final submission |

**Benchmark (measured on the board):**

| Task | Model / tool | Version | Result |
|---|---|---|---|
| Person + pose | YOLO11n-pose (Bayes-e `.bin`) | RDK OS 3.x / hbdk | ~**19.5 FPS** |
| STT | sherpa-onnx **SenseVoice** multilingual int8 + Silero VAD | onnxruntime | real-time (CPU) |
| LLM | TinySwallow-1.5B Q5_K_M *(Qwen2.5-1.5B-based)* | llama.cpp | load 24 s, **1.5–3.3 tok/s** |
| TTS (JP) | Open JTalk (pitched) | apt | instant |
| Thermal — full stack, LLM at ~600 % CPU | — | `hrut_somstatus` | CPU/BPU/DDR **≈50–51 °C** (<60 °C ✅) |

> **BPU-acceleration proof:** YOLO11n-pose runs as a compiled Bayes-e `.bin` on the BPU
> (`hrut_somstatus` shows non-zero `bpu0` utilisation during inference); the LLM stays on
> the 8× A55 CPU **by design** (see [docs/rdk_x5_bpu_llm.md](docs/rdk_x5_bpu_llm.md)).

## 10. Reproduce

```bash
# On the RDK X5 — everything is one integrated service, auto-starting on boot:
sudo systemctl status korosuke-monitor   # camera+pose+STT+LLM+TTS+eyes+arms
#   → open http://<board-ip>:8080  (Monitor / Settings tabs)
# Safe shutdown: hold the GPIO button ~1 s (goodnight voice → ✕✕ eyes → halt).
```
Component research + decisions:
[docs/dialogue_stack_research.md](docs/dialogue_stack_research.md) (LLM/TTS),
[docs/stt_research.md](docs/stt_research.md) (STT),
[docs/rdk_x5_bpu_llm.md](docs/rdk_x5_bpu_llm.md) (why BPU-LLM is S100-only),
[docs/mocap_capabilities.md](docs/mocap_capabilities.md) (gesture),
[docs/implementation_plan.md](docs/implementation_plan.md) (roadmap),
[docs/TESTING.md](docs/TESTING.md) (test commands),
[docs/diary/](docs/diary/) (build log).

---
*"ワガハイはコロ助ナリ！" — fully on-device, powered by RDK X5.*
Character © Fujiko F. Fujio — fan-made, non-commercial tribute.

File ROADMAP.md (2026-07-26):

# Project Korosuke — Roadmap

**Version 1.0 · 2026-07-05** · D-Robotics Robotics Dream Keeper Challenge
Brain: **RDK X5** (10 TOPS BPU, ROS 2). Full design rationale in [PROPOSAL.md](PROPOSAL.md).

Final submission check: **2026-07-26 14:30 GMT**. Stage 3 showcase: [STAGE3.md](STAGE3.md).

---

## Status legend
✅ done · 🔄 in progress · ⬜ planned · ✴️ stretch (decoupled, never on critical path)

## Milestones

| # | Window | Milestone | Exit criterion | State |
|---|---|---|---|---|
| M0 | –6/24 | **Stage 1 — Ignite** | RDK X5 boots, on-device YOLO11 on BPU, thermal solved, open-source case shipped | ✅ |
| M1 | 6/25–7/5 | **Stage 2 — Build** design | Concept + AI architecture + ROS 2 graph + BOM + roadmap + risks, submitted as showcase PR | ✅ |
| M1b | (parallel) | **Hardware / 3D body** | Full body redesigned for color-split printing; eye + chest-camera mounts | ✅ |
| M1c | (parallel) | **Eye coprocessor bring-up** | 2× GC9A01 driven by ESP32-S3 (LovyanGFX), emotions/gaze/blink over UART | ✅ |
| M2 | 7/5–7/7 | **ROS 2 skeleton** | ROS 2 Humble on RDK X5; `korosuke_msgs`; `serial_bridge` moves the eyes from a topic | ✅ (eye_demo→bridge→eyes verified) |
| M3 | 7/8–7/11 | **Perception + dialogue** | vision (BPU)→gaze tracking; **on-device** STT(sherpa)+LLM(TinySwallow)+TTS(OpenJTalk) "…ナリ"; expression | ✅ (VOICEVOX→OpenJTalk; on-device LLM added) |
| M4 | 7/12–7/13 | **Integrated demo** | see → turn → greet → emote → gesture, fully on-device; benchmark table | ✅ (the `korosuke-monitor` service; +arm actuation, gestures) |
| M5 | 7/14– | **Stage 3 — Launch** | demo video; benchmark; Stage 3 showcase | 🔄 [STAGE3.md](STAGE3.md) + README Quick Start + benchmarks + ROS 2 graph + failure-recovery docs all done; **demo video done ([youtu.be/NJwj6Iazd20](https://youtu.be/NJwj6Iazd20)); showcase PR pending** |
| S1 | if time | **Bipedal gait** | quasi-static "penguin" gait, 3+ steps, no fall — *only if* the junk QDD motors revive | ✴️ |

## Acceptance criteria (measurable goals)

Mapped from [PROPOSAL.md §1.3](PROPOSAL.md):

- **G1 Vision:** ≥10 FPS sustained on BPU; detection→action latency <150 ms.
- **G2 Gaze:** eyes + neck follow a face, error <5° after 300 ms. — *as-built: **eyes-only** (no neck servo fitted); neck-follow deferred.*
- **G3 Voice:** wake → LLM → speech start <3.0 s; "…nari" style. — *on-device STT→LLM→TTS built; LLM reply is 5–10 s on CPU (BPU can't accelerate LLM on X5), covered by the "thinking" eyes.*
- **G4 Lip-sync:** mouth follows audio envelope within 100 ms. — ***not implemented*** *(no 2-axis mouth mechanism); expression is via the eyes + voice instead.*
- **G5 Eye emotion:** ≥30 FPS on 2× GC9A01, 7 emotions.
- **G6 Thermal:** sustained BPU+CPU+vision <60 °C (fan lid validated at Stage 1).
- **G7 Bipedal ✴️:** quasi-static gait, 3+ steps (stretch only).

## Top risks (see [PROPOSAL.md §3.4](PROPOSAL.md) for the full table + triggers)

1. **QDD motors are junk** → bipedal is a decoupled stretch; MVP passes seated/standing.
2. **LLM/VOICEVOX latency** → async off the perception loop + canned "…nari" fallbacks.
3. **2× GC9A01 @30 FPS load** → dedicated ESP32-S3 coprocessor, not the RDK.
4. **Thermal throttling** → fan lid (−17 °C) validated; monitor `hrut_somstatus`.
5. **Timeline (7/15 is tight)** → MVP-first; reuse existing firmware/server; integration front-loaded.

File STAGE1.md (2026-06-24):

# Project Korosuke — Stage 1 (Ignite): "Power On Your AI Robot's Brain"

Stage 1 write-up for the **D-Robotics Robotics Dream Keeper Challenge**.
Goal: go from first powering an **RDK X5 (8GB)** to running an on-device AI task.

**Board:** D-Robotics RDK X5 8GB · Sunrise X5 SoC · 10 TOPS BPU · Ubuntu 22.04 (RDK OS 3.5.0) · aarch64
**Hostname:** `korosuke`

---

## Challenge 1 — Wake the board

### 1. Flash the OS
- Image: **RDK OS 3.5.0** (Ubuntu 22.04 Desktop, RDK X5), written to a microSD card.
- Tool: **Raspberry Pi Imager** (Etcher failed mid-write on this machine; Imager succeeded).
- Verified the download integrity by MD5 before flashing (`b39cd58ab65e838929063e4f1e184d0b`).

### 2. Network
- Connected over **Wi-Fi**; board obtained `192.168.0.138` on the LAN.
- Connectivity check:
  ```bash
  ping -c3 8.8.8.8
  curl -sI https://archive.d-robotics.cc | head -1
  ```

### 3. SSH login
```bash
# password login (default user/pass: sunrise / sunrise)
ssh sunrise@192.168.0.138

# key-based login (after copying a public key)
ssh-copy-id -i ~/.ssh/id_ed25519_robosta.pub sunrise@192.168.0.138
ssh -i ~/.ssh/id_ed25519_robosta sunrise@192.168.0.138
uname -a    # Linux korosuke 6.1.83 ... aarch64
```

### 4. Board bring-up / optimization
- Timezone → `Asia/Tokyo`, hostname → `korosuke`.
- Connected the board to the **RDK Studio** desktop app (device shows *online · SSH verified*).
- Verified the BPU is healthy: `/dev/bpu`, `/dev/bpu_core0`, `/dev/ion` present; `sudo hrut_somstatus` reports BPU/CPU/DDR temps and frequencies.

### 5. Community
- Joined the official Discord and posted an introduction / Stage 1 thread.

---

## Challenge 2 — Sensor Explorer (USB camera)

A generic **UVC USB camera** (`USB Composite Device: DV20 USB`, USB ID `4c4a:4a55`) is
recognized out of the box by the `uvcvideo` driver as `/dev/video0`.

```bash
# enumerate
v4l2-ctl --list-devices
v4l2-ctl --device=/dev/video0 --list-formats-ext   # MJPG/YUYV 640x480@30fps

# capture a single preview frame (discard warm-up frames first)
python3 - <<'PY'
import cv2, time
cap = cv2.VideoCapture(0, cv2.CAP_V4L2)
cap.set(cv2.CAP_PROP_FOURCC, cv2.VideoWriter_fourcc(*"MJPG"))
cap.set(cv2.CAP_PROP_FRAME_WIDTH, 640); cap.set(cv2.CAP_PROP_FRAME_HEIGHT, 480)
for _ in range(12): ok, f = cap.read(); time.sleep(0.04)   # UVC warm-up
cv2.imwrite("/tmp/cam_preview.jpg", f)
PY
```

**Interface:** USB / V4L2 (`uvcvideo`) · **Evidence:** [`docs/stage1_evidence/B_camera_preview.jpg`](docs/stage1_evidence/B_camera_preview.jpg)

---

## Challenge 3 — First AI Task (YOLO11 object detection on the BPU)

The board ships with the D-Robotics demo suite at `/app/pydev_demo/` including
pre-compiled BPU models (`.bin`) for YOLO11 / v8 / v10 / v5.

### Static image (sanity check)
```bash
cd /app/pydev_demo/02_detection_sample/02_ultralytics_yolo11
python3 ultralytics_yolo11.py --img-save-path /tmp/yolo_result.jpg
# -> draws person/kite boxes on kite.jpg, ~3 s including model load
```

### Live USB camera → BPU → detection
A small script reuses the sample's `YoloV11` runtime wrapper
(`hbm_runtime.HB_HBMRuntime`) and feeds it live camera frames:

```bash
cd /app/pydev_demo/02_detection_sample/02_ultralytics_yolo11
python3 cam_yolo.py   # see scripts/cam_yolo.py in this repo
```

- Model: `yolo11n_detect_bayese_640x640_nv12.bin` (YOLO11-nano, Bayes-e quantized for RDK X5).
- Pipeline: `pre_process()` → NV12 → `forward()` on **BPU core 0** → `post_process()` (dequant + NMS).
- Measured **~8.3 FPS** end-to-end (USB capture + MJPG decode + BPU inference + draw);
  capture/decode is the bottleneck, BPU inference alone is faster.
- Live detections in the workspace: `person 0.94`, `laptop 0.50`, `backpack 0.56`, `chair`, `suitcase`.

**On-device (not on a PC).** **Evidence:** [`docs/stage1_evidence/C_yolo_live_detection.jpg`](docs/stage1_evidence/C_yolo_live_detection.jpg)

---

## Thermals (why this matters for a robot)

Passive (no case lid, no fan) the board idled at **~66 °C** (DDR/BPU/CPU).
Adding a 5 V 40 mm fan powered from the **40-pin header (pin 4 = 5V, pin 6 = GND)**
dropped it to **~45–49 °C** — important headroom before running YOLO under load.
A purpose-built fan lid is part of the open-source case below.

---

## Dependencies

All pre-installed on RDK OS 3.5.0 — nothing extra to `pip install` for this stage:

| Component | Notes |
|---|---|
| `hobot_dnn` / `hbm_runtime` | D-Robotics BPU runtime (Python) |
| `python3` (3.10) + `opencv-python` (`cv2`) | capture + drawing |
| `v4l2-utils` (`v4l2-ctl`) | camera enumeration |
| `hrut_somstatus` | board temp / freq telemetry |
| Demo suite | `/app/pydev_demo/` (ships with the OS image) |

---

## Related open-source output

As a by-product of this stage I designed and published the **first open-source
3D-printable case for the RDK X5** (one base + closed / open / VESA / **fan** lids),
fully parametric OpenSCAD: **https://github.com/gurimaruking/rdk-x5-modular-case** (CC BY 4.0).

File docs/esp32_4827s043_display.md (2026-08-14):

# コロ助 胴体ディスプレイ — ESP32-4827S043 設計・実装・引き継ぎ資料

> **性格:** korosuke の顔/目とは別に、**胴体に4.3インチのタッチ液晶**を追加し、
> **RDK X5のカメラ映像をUSB経由で表示**＋**タッチで制御**するサブシステムの設計書。
> 記載のうち「✅実機検証済」は本PC(Windows)＋実基板＋RDK実カメラで確認済み。
> 「調査」はWeb一次情報からの裏取り（出典URLは末尾）。**別PC/エージェントが続きを実装できるように**書いてある。
>
> 作成: 2026-07-28 / 対象基板: **Sunton ESP32-4827S043R**(抵抗膜タッチ版) / ブランチ: `stage3-launch`

---

## 0. TL;DR（3行）

- **基板 = Sunton ESP32-4827S043R**(CYD系, ESP32-S3 N16R8, 480×272 RGBパラレル, **抵抗膜XPT2046タッチ**)。USB-Cは**CH340C UART**配線 → Windowsで`COM16`、RDK Linuxで`/dev/ttyUSB*`。
- **経路 = RDKカメラ → LAN(or直接) → `display_send.py` → USBシリアル(2Mbaud) → ESP32が受信・JPEGデコード・描画**。プロトコルは `A5 5A | len(u32LE) | JPEG` ＋ フレーム毎ACK。
- **現状 = M0(表示)/M1(タッチ)/M2(USB映像) まで実機で動作確認済み ✅（~5–6fps）**。残り = fps最適化(JPEGDEC+並列)・M3タッチ制御・RDK直結デプロイ（**RDKにはS3が2枚あるのでポート選別注意**）。

---

## 1. ゴールと現状

**やりたいこと:** korosuke のカメラ（RDK X5にUSB接続されたUVCカメラ、YOLO/骨格描画済み）で受け取った映像を、胴体の ESP32-4827S043 に表示する。タッチもあるので、タッチで korosuke を制御する。最終的には **RDK X5からUSB経由**で映像・制御を完結させる（ネット非依存＝korosukeの思想と一致）。

| マイルストン | 内容 | 状態 |
|---|---|---|
| **M0** | RGBパネル点灯・テストパターン | ✅ 実機OK（色順・タイミング正常） |
| **M1** | 抵抗膜タッチ(XPT2046)読み取り | ✅ 実機OK（`pin_int=-1`ポーリングで解決） |
| **M1b** | タッチ四隅キャリブレーション＋NVS保存 | ✅ 実機OK（デモボタン命中確認） |
| **M2** | USBシリアルでJPEG受信→デコード→表示 | ✅ 実機OK（RDK実カメラのライブを目視確認, ~5–6fps） |
| **M2opt** | fps最適化 | 🟡 **JPEGDEC(SIMD)化 実機OK ✅**（デコード~2倍/帯域44→95KB/s、色は`RGB565_BIG_ENDIAN`）。デュアルコア並列は未 |
| **M3** | タッチボタン→USB経由でRDK制御(`/eye` `/arm` `/say`) | ⬜ 未（設計は §10） |
| **DEPLOY** | RDK X5直結（`display_send.py`をRDKで常駐） | ✅ **実機OK** — RDK単独・完全USB・ネット非依存で常時表示（手順 §8） |
| **回転** | Web設定から入力/表示映像の回転(0/90/180/270) | ✅ **実機OK** — dashboard **⚙設定→🖥胴体ディスプレイ向き**。`/dispcfg`経由でdisplay_send.pyが約1秒で反映。中核系(YOLO/目)無干渉 |

---

## 2. 基板の確定情報（✅一部実機検証 / 調査）

### 2.1 正体・コアスペック
- **メーカー/系統:** Sunton、"Cheap Yellow Display (CYD)" ファミリの4.3インチ機。型番デコード `4827`=480×272, `S043`=4.3"、末尾 **R=抵抗膜(XPT2046)** / C=静電(GT911) / 無=タッチ無し。**本機はR（抵抗膜）**。
- **SoC:** ESP32-S3-WROOM-1 **N16R8**（デュアルLX7 @240MHz, WiFi2.4GHz+BLE）。✅実機: `PSRAM 8386279B(≈8MB, Octal)`, `Flash 16MB`, MAC `f4:12:fa:e2:06:4c`, rev v0.1。
- **USB-C:** **CH340C UART ブリッジ専用**（`VID_1A86&PID_7523`）。✅実機: Windowsで `USB-SERIAL CH340 (COM16)`。**ネイティブUSB(ttyACM)は出ない**＝USB-Cはシリアルのみ（調査でも「USB-C→Serial0(CH340C)」と一次情報一致）。
- **⚠️ 紛らわしい別物:** Guition **JC4827W543**（同じ480×272/4.3"だが QSPI/NV3041A/4MB/IPS）。**別基板・別ドライバ**。混同しないこと。
- **入手・価格（調査 2026-07）:** AliExpress の Sunton ストアが主。本機(480×272)の出品で **$14.15** の実例あり。抵抗膜(R)版は概ね **$14–18（≈¥2.2–2.8k）**、静電(C)版は数ドル高、無タッチ版が最安。BOMには**Option**として登録済（[stage2_design.md §3.1](stage2_design.md)）。出典: esp3d.io の購入リンク先 AliExpress 1005004788147691 / Surenoo / Makerfabs。

### 2.2 ピン配置（✅本リポの firmware がこの値で動作）

**RGBパネル（16bitパラレル, ST7262系, init不要）** — 出典 Arduino_GFX #587 / LovyanGFX同梱 `LGFX_ESP32S3_RGB_ESP32-8048S043.h`（兄弟機同ピン）:

| 信号 | GPIO | | 信号 | GPIO |
|---|---|---|---|---|
| DE (henable) | 40 | | Green d5–d10 | 5,6,7,15,16,4 |
| VSYNC | 41 | | 5bit群A | 8,3,46,9,1 |
| HSYNC | 39 | | 5bit群B | 45,48,47,21,14 |
| PCLK | 42 | | Backlight(PWM) | 2 |

> 群A/群Bのどちらをr/bと呼ぶかはライブラリのカラーオーダ次第。**本リポ設定（A=Blue d0-4, B=Red d11-15）で色は正常** ✅（赤青逆なら入替）。タイミング: PCLK 9MHz, HSYNC fp8/pw4/bp43, VSYNC fp8/pw4/bp12, `pclk_active_neg=1`。

**抵抗膜タッチ XPT2046（SPI, ✅実機動作）** — 出典 rzeldent `esp32-4827S043R.json`:

| 信号 | GPIO | 備考 |
|---|---|---|
| SCLK | 12 | **microSDと共有** |
| MOSI | 11 | **microSDと共有** |
| MISO | 13 | **microSDと共有** |
| CS | 38 | タッチ専用（SDのCS=10と別） |
| IRQ/PENIRQ | 18 | **⚠️基板上で未結線気味 → `pin_int=-1`必須（§12参照）** |
| SPIホスト | SPI2_HOST | clock ≤2.5MHz（本リポ1MHz） |

**microSD:** CS=10, MOSI=11, SCK=12, MISO=13（タッチとバス共有、CSのみ別）。
**ネイティブUSB(未使用):** GPIO19=D-, GPIO20=D+（IOMUX固定）。R版ではタッチが19/20を使わないので**空いている**が、USB-Cは繋がっていないため**使うには背面ヘッダP3へUSB線を半田付け必要**（§9のPath B）。

---

### 2.3 コネクタ / ケーブル（調査 2026-07）
CYD系の**1.25mm 4ピン**コネクタは **Molex PicoBlade（MX1.25）**。**JST GHではない**（GHも1.25mmだが**嵌合しない**）。俗に「JST 1.25」と誤称される。

| コネクタ | ピッチ/系列 | ピン | 配列 | 適合ケーブル |
|---|---|---|---|---|
| **P1** UART/電源 | 1.25mm PicoBlade | 4 | GND / RX(IO44) / TX(IO43) / +5V | 1.25mm 4P |
| **P2** SPI(SD) | 1.25mm | 4 | IO13 / IO12 / IO11 / IO19 | 1.25mm 4P |
| **P3** USB/UART | 1.25mm | 4 | IO20 / IO19 / IO18 / IO17（19/20=ネイティブUSB D-/D+） | 1.25mm 4P |
| **P4** IO | 1.25mm | 4 | IO18 / IO17 / +3.3V / GND | 1.25mm 4P |
| **I2C**(S3機のみ) | **1.0mm JST SH** | 4 | SDA/SCL/3V3/GND | 1.0mm 4P(Qwiic形状・ピン順要確認) |
| **SPEAK** スピーカ | 1.25mm PicoBlade | 2 | アンプ出力(8Ω) | 1.25mm 2P |
| USB-C | — | — | CH340C(給電+シリアル) | USB-Cケーブル |

- **買うもの:** 「**1.25mm 4P / MX1.25 / PicoBlade**」。**「JST GH」は非嵌合で不可**、**「JST PH(2.0mm)」も不可**。スピーカは2P版。S3機のI2Cのみ1.0mm(JST SH)。基板に4Pケーブル1本同梱が多い。
- 電池コネクタ/充電回路は**無し**（給電=USB-C か P1の+5V）。バックライト/RGB LEDは内部GPIO（コネクタ無し, BL=IO2）。
- ⚠️ 安価ケーブルは**ストレート/リバース混在**（5V/GND逆の恐れ）→通電前に導通確認。SMD端子は脆いので**線でなくプラグを持つ**。
- ⚠️ S3機(4827/8048)の1.25mmがPicoBlade正規かGH互換クローンかは実測未確認（2432S028で確認、同一OEMとしてfamilyに敷衍）。
- 出典: witnessmenow CYD PINS.md / rzeldent board defs / esp3d.io / espboards.dev。

---

## 3. リポジトリ構成（今回追加したもの）

```
firmware/corosuke_display/           ← 新規PlatformIOプロジェクト
  platformio.ini                     ← ESP32-S3 N16R8 / LovyanGFX 1.1.16 / upload_port=COM16
  src/
    LGFX_ESP32_4827S043.h            ← LovyanGFXパネル+タッチ定義(この基板の“唯一の正”)
    main.cpp                         ← 現在 M2(USB JPEGビューア)。M0/M1は履歴で差し替え済
tools/
  display_send.py                    ← 送信側(PC/RDK共用)。test/cam/file/mjpeg。
                                       --port auto(VID/PID選別) / drop-to-latest(低遅延) / USB自動再接続 / --list
  rdk_display_start.sh               ← RDK常駐起動ヘルパ(nohup)。start / stop
  rdk_display_flash.sh               ← CYDファーム遠隔フラッシュ(0x10000のみ)。焼く前にポート=1a86:7523を検証(目基板保護)
docs/
  esp32_4827s043_display.md          ← 本書
```

既存の目ファーム（`firmware/corosuke_eyes/`, LovyanGFX 1.1.16, ESP32-S3 N16R8）と**同じ流儀**で作ってある。目ファームは無改造・別基板のまま。

---

## 4. ビルド & 書き込み（Windows / PlatformIO）

```powershell
# PlatformIO Core は既にインストール済 (C:\Users\User\.platformio\penv\Scripts\pio.exe)
$pio = "$env:USERPROFILE\.platformio\penv\Scripts\pio.exe"

# ビルド＆書き込み（COM16固定。ポートが変わったら §下の自動検出で調べて platformio.ini を修正）
& $pio run -d "firmware\corosuke_display" -t upload

# CH340ポート自動検出（挿し直しでCOM番号が変わった時）
Get-PnpDevice -Class Ports -PresentOnly | Where-Object InstanceId -match 'VID_1A86&PID_7523'
```

- `platformio.ini`: `board=esp32-s3-devkitc-1`, `memory_type=qio_opi`(Octal PSRAM), `flash_size=16MB`, `-DBOARD_HAS_PSRAM -DLGFX_USE_V1`, `lib_deps=lovyan03/LovyanGFX@1.1.16`。
- **USB CDCは使わない**（`ARDUINO_USB_CDC_ON_BOOT`未設定）→ `Serial`はUART0=CH340に出る。これで映像・制御・ログが**CH340の1本**で完結。
- 書き込み後のシリアル確認（起動バナー捕捉のためEN=RTSパルス）:
  ```powershell
  $p=New-Object System.IO.Ports.SerialPort 'COM16',115200,'None',8,'One'; $p.Open()
  $p.RtsEnable=$true; Start-Sleep -ms 120; $p.RtsEnable=$false
  1..40 | %{ try{$p.ReadLine()}catch{} }; $p.Close()
  ```
  ※M2実行時のアプリ`Serial`は**2000000 baud**（`BAUD`定数）。監視も2Mに合わせること。

---

## 5. USB映像プロトコル（✅実機動作）

送信(`display_send.py`) → ESP32 の1フレーム:
```
0xA5 0x5A            同期マジック(2B)
len  (uint32 LE)     続くJPEGのバイト数
<len bytes>          JPEG本体(480x272想定、そのまま全画面drawJpg)
```
- ESP32は**1枚デコード完了ごとに `0x06`(ACK) を返す**。送信側はACKを待ってから次を送る＝**フロー制御**（CH340はHWフロー制御線が無いので、これが無いとRXバッファ溢れで破損する）。
- ESP32のテキストログ(`fps=...`)は同じTXに混ざるが、ACKは制御コード`0x06`なのでテキスト(ASCII)と区別可能。
- **ボーレート=2,000,000**（CH340C実力上限。✅2Mでバナー・映像とも安定）。

**送信スクリプト使用例:**
```bash
# 合成アニメ（カメラ不要・パイプライン検証）
python tools/display_send.py --port COM16 --source test --duration 15
# RDKの実カメラMJPEGをLAN越しに引いてUSBへ中継（Windows検証で使用）✅
python tools/display_send.py --port COM16 --source "mjpeg:http://192.168.0.200:8080/stream"
# webカメラ / 動画ファイル
python tools/display_send.py --port COM16 --source cam:0
python tools/display_send.py --port COM16 --source movie.mp4
```
オプション: `--baud`(既定2000000) `--quality`(既定60) `--fps`(送信上限) `--width/--height`(既定480/272) `--duration`(0=無限)。

---

## 6. コロ助サーバとの統合面（重要 — サーバ改造ほぼ不要）

RDK X5のダッシュボード `scripts/korosuke_monitor.py`（HTTP :8080）が**既に必要なものを全部REST/HTTPで公開**している:

| 用途 | エンドポイント | 実体 |
|---|---|---|
| 映像を引く | `GET /stream` | MJPEG(`multipart/x-mixed-replace; boundary=FRAME`)。YOLO枠+骨格入り**640×480 JPEG q80 ≈20fps** ([korosuke_monitor.py:1641](../scripts/korosuke_monitor.py#L1641)) |
| 表情 | `GET /eye?emo=happy&blink` | 目ESP32へ転送 ([:1589](../scripts/korosuke_monitor.py#L1589)) |
| 腕 | `GET /arm?do=wave` / `l=<deg>&r=<deg>&off=both` | 腕サーボ ([:1597](../scripts/korosuke_monitor.py#L1597)) |
| 発話 | `GET /say?text=...` / `GET /llm?text=...` | Open JTalk / ローカルLLM ([:1572](../scripts/korosuke_monitor.py#L1572)) |
| 状態 | `GET /events` (SSE) | cam/yolo/present/speech 等JSON |

→ **M3タッチ制御は、これらを叩くだけ**（§10）。USB直結時はESP32→RDKへ制御要求を送り、RDK側の小デーモンがこのRESTを叩く（or 直接pyserialで目ESP32へ）。

**任意のサーバ改修（fpsを稼ぐなら推奨）:** `camera_loop`の`imencode`直前で`cv2.resize(frame,(480,272))`する縮小版ストリーム（例 `/stream?w=480`）を足すと、S3のデコード負荷が~3倍軽くなりfpsが上がる（[korosuke_monitor.py:494](../scripts/korosuke_monitor.py#L494)付近）。現状は`display_send.py`側でresizeしているので必須ではない。

---

## 7. コロ助側の接続前提（実装確認済みの事実）

- カメラ = RDK X5にUSB接続のUVCカメラ（640×480 MJPG）。映像処理・配信はRDK上のPython。
- RDK ⇄ 目ESP32 は既に **USB-CDCシリアル 115200 のテキスト行**で通信（`serial_bridge_node.py`, `korosuke_monitor.py`のEyesクラス）。**本ディスプレイはその隣に増設**する2台目のUSB子機。
- RDK実機IP（本作業時点）: **`192.168.0.200`**（ダッシュボード `http://192.168.0.200:8080/` 到達確認済 ✅）。

---

## 8. RDK X5 直結デプロイ手順（最終形）— ⚠️**S3が2枚ある罠** ✅実施済

> **✅ 2026-07-29 実機で成立:** RDK(`192.168.0.200`)上で `tools/rdk_display_start.sh` を実行 → `display_send.py --port auto` が
> **`/dev/ttyUSB0`(1a86:7523=ディスプレイ)** を自動選別（目基板`/dev/ttyACM0`=1a86:55d3 は非対象）→ ローカル`:8080/stream`(処理済み映像)を
> USBでCYDへ**常駐配信**(nohup, SSH切断後も継続)。~3.7–4.6fps(デコード律速, 画面の細かさで変動)。**ネット非依存・RDK単独。**
>
> 起動: `bash ~/rdk_display_start.sh` / 停止: `bash ~/rdk_display_start.sh stop` / ログ: `~/display_send.log`。
> 恒久化(ブート時自動起動)は systemd unit 化（`deploy/`に`korosuke-monitor.service`の前例）。

**最重要注意（ユーザ指摘）:** RDK X5には **ESP32-S3が2枚**繋がる — ①既存の**目**コプロセッサ、②本**ディスプレイ**。RDK上では両方が `ttyUSB*`/`ttyACM*` に出るため、**`display_send.py` のポートを間違えると目のファームを壊す/映像を目基板へ流してしまう**。必ず見分けること:

| 基板 | ブリッジ | Linuxでの見え方 | VID:PID |
|---|---|---|---|
| **ディスプレイ(本機)** | CH340C | `/dev/ttyUSB*`（ch341ドライバ） | **1a86:7523** |
| **目(eyes)** | CH343 or ネイティブUSB | `/dev/ttyACM*`（cdc_acm） or `/dev/ttyUSB*`(CH343=**1a86:55d3**) | 303a:1001 or 1a86:55d3 |

**ポート特定（RDK上, PID厳密指定）:**
```bash
# ディスプレイ(CH340=1a86:7523)のttyを厳密に特定
for d in /sys/bus/usb-serial/devices/*; do
  dev=/dev/$(basename $d)
  info=$(udevadm info -q property -n $dev)
  echo "$info" | grep -q 'ID_VENDOR_ID=1a86' && echo "$info" | grep -q 'ID_MODEL_ID=7523' && echo "DISPLAY = $dev"
done
```
`display_send.py`にVID/PID自動選別を実装するのが安全（**TODO:** `--auto-vidpid 1a86:7523`）。現状は`--port`明示なので、上記で特定した`/dev/ttyUSB*`を渡すこと。**目基板のポートを絶対に渡さない。**

**RDKでの起動（自分のカメラを自分に流す＝USB完結）:**
```bash
# 依存: pyserial + opencv（korosuke_monitorが既にcv2使用 → 入っている）
python3 tools/display_send.py --port /dev/ttyUSB_DISPLAY --source cam:0
# もしくは既存の処理済みMJPEGをローカルで引く（YOLO/骨格入りを出したい場合）
python3 tools/display_send.py --port /dev/ttyUSB_DISPLAY --source "mjpeg:http://127.0.0.1:8080/stream"
```
- ファーム書き込みをRDKから行う場合も**同じポート罠**に注意（`pio`不在なら、Windowsでビルドした`firmware.bin`を`scp`して`esptool.py --port /dev/ttyUSB_DISPLAY write_flash ...`）。**目基板ポートへ焼かない。**
- 常駐化はsystemd unit（`deploy/`に`korosuke-monitor.service`の前例あり）を用意すると良い。

---

## 9. 既知の課題 & 最適化ロードマップ

### 9.1 fps の内訳と改善
- **✅ JPEGDEC(SIMD)化 実施済** — `lcd.drawJpg`(内蔵tjpgd) → **bitbank2/JPEGDEC** に置換。MCUブロックcallbackで`lcd.pushImage`。**帯域 44→95 KB/s(約2倍)**。実測 ~6fps（ただし配信画面が細かく16KB/フレームのため。~10KBの絵なら~9-10fps）。
  - **重要:** JPEGDECの出力は **`RGB565_BIG_ENDIAN`** にすること（LovyanGFX pushImageの期待に一致）。LITTLEだと色化け(バイト逆)で「汚い」映像になる（§12）。実装は [main.cpp](../firmware/corosuke_display/src/main.cpp) の `jpegDraw` callback + `jpeg.setPixelType`。
- **残りの改善策:**
  1. **デュアルコア並列化**（未） — core0=シリアルRX（PSRAMリングへ）, core1=デコード+描画。ACK維持＋ダブルバッファで転送とデコードを重ねる → +50%程度。
  2. **JPEG品質を下げる**（`display_send.py --quality 45`）→ フレーム小→転送&デコード速→fps↑（画質とトレード）。ファーム不要。
  3. **RDK側で480×272縮小配信**（§6）→ デコード対象画素が減りさらに軽い。
- 遠隔での焼き直し: Windowsで`pio run`→`firmware.bin`をscp→`bash rdk_display_flash.sh`（アプリ0x10000のみ・ポート検証付き）→`bash rdk_display_start.sh`。
- **native USB(Path B)** に載せ替えると帯域は12Mbps（実効~0.5–1MB/s）に上がるが、**背面ヘッダP3へUSB線半田付けが必要**（USB-CはCH340専用）。それでも**デコード律速で~20–30fpsが上限**。CH340のままJPEGDEC化で~15fps出れば胴体表示には十分、というのが妥当な判断。

### 9.2 描画（RGBパネル）メモ
- LovyanGFX `Panel_RGB` はPSRAMフレームバッファを連続スキャン。`fillRect`/`drawString`/`drawJpg`いずれも`_frame_buffer`へ書いて`cacheWriteBack`する実装で、**本機では`drawJpg`も正常描画** ✅（当初「映らない」はストリーム終了後に見ていた誤認だった）。
- 参考: LovyanGFX #374 に800×480機で`writePixels`の再描画不完全（PSRAM帯域症状）報告あり。480×272では未発現。もし将来tearing/欠けが出たら、esp_lcdのbounce-bufferや部分更新を検討。

### 9.3 タッチ
- **キャリブレーションは個体ごと必須**（抵抗膜）。本リポは`calibrateTouch()`結果を**NVSに保存**（`koro-disp/touchcal`）→ 再フラッシュしても保持（NVSはアプリ領域と別パーティション）。Serialに`c`送出で再キャリブ。
- SDカードを使う場合は`bus_shared=true`にする（タッチとSDがSPI2共有）。**本FWはSD未使用なので`bus_shared=false`でOK** ✅。

---

## 10. M3: タッチ制御 設計（別PC実装用）

**狙い:** 画面下部にボタンを重ね、タッチ→USB経由でRDKへ制御要求→RDKが既存REST(`/eye` `/arm` `/say`)を叩く。M1bで**ボタン命中判定は実証済み**（`main.cpp`のBtn配列＋矩形ヒットテスト）。

**プロトコル（ESP32→RDK, 逆方向）:** 映像フレームと衝突しないよう、行テキストで送る:
```
CTL eye happy        → RDK: GET /eye?emo=happy&blink
CTL arm wave         → RDK: GET /arm?do=wave
CTL say <text>       → RDK: GET /say?text=<text>
```
- ESP32側: タッチでボタン確定 → `Serial.printf("CTL %s\n", cmd)`。ACK(0x06)とは別チャネル（テキスト行）。
- RDK側: `display_send.py`（or 相棒デーモン）が同じシリアルを**読み**、`CTL ...`行を見たら`requests.get("http://127.0.0.1:8080/eye?...")`を叩く。※`display_send.py`は既にESP32のテキスト行を読んでログ表示しているので、そこに`CTL`ハンドラを足すだけ。
- **UIレイアウト案:** 上=映像(480×~220)、下=ボタン帯(3–4個: 😊表情 / 👋手を振る / 🗣定型セリフ / 設定)。映像とUIの重畳は、映像を上部矩形にクリップ描画し、下帯は固定UIにする。

---

## 11. カメラ＋ディスプレイ一体型MCU 調査（ユーザ依頼）

**結論:** 一体型は**自分のカメラ**を映すのが本分。korosukeの狙いは**RDKの処理済み映像を映す**ことなので、一体型のカメラは基本デッドウェイト。**受信して映すだけなら display-only（＝今の Sunton 4827S043）で十分**。唯一「映像受信」が快適なのは **ESP32-P4**（ハードJPEG＋USB-HS）。

| ボード | カメラ | ディスプレイ | HW JPEG | USB | 概算 | 位置づけ |
|---|---|---|---|---|---|---|
| **ESP32-P4-Function-EV** ⭐ | 2MP MIPI | 7" 1024×600 タッチ | **有(640×480@307fps)** | **HS 480Mbps** | ~$55 | 映像受信が唯一余裕。WiFiは相棒C6経由。7"は顔には大きい |
| ESP32-P4-Nano(Waveshare) | MIPI端子 | DSI端子(別売) | 有 | HS | ~$40–50 | 小型パネルと組むならP4の最良形 |
| **M5Stack CoreS3** | 0.3MP GC0308 | 2.0" 320×240 タッチ | 無 | FS | ~$60 | M5で唯一カメラ+画面両載せ。筐体◎。native-USBは目S3と同じDLリセット罠 |
| **ESP32-S3-EYE** | 2MP OV2640 | 1.3" 240×240 | 無 | FS | ~$45–50 | UVC送出＋MJPEG受信表示の公式サンプルあり＝流用しやすい |
| LilyGo T-Camera-Plus-S3 | 2MP/5MP(暗視) | 1.3" 240×240 タッチ | 無 | FS | ~$35–45 | 一体型として手頃 |
| Sipeed MaixCAM-Pro ⭐ | 5MP | 2.4" 640×480 タッチ | (Linux/NPU) | — | ~$55–88 | **自前でAIする“考える目”**。ESP32ではなくLinux AIカメラ |
| (参考)Seeed XIAO S3 Sense | 2MP | **無** | 無 | FS | ~$14–20 | カメラのみ・画面無し |
| (参考)M5 CoreS3 **SE** | **無(削除)** | 2.0"タッチ | 無 | FS | ~$39 | ※SEはカメラ非搭載。混同注意 |

- **RDK映像をUSBで受けるなら:** ①ESP32-P4系（余裕）②ESP32-S3-EYE（サンプル流用）③**今の4827S043で十分**。
- **自己完結の“目”にするなら:** ①MaixCAM-Pro ②M5 CoreS3 ③S3-EYE。
- **要点:** 「映像をデコードして受ける」なら **ESP32-P4だけがハードJPEG＋USB-HSで別格**。S3系は全てソフトJPEG＋USB-FS(12Mbps)。

---

## 12. トラブルシュート集（今回ハマった実例）

| 症状 | 原因 | 対策 |
|---|---|---|
| ビルドエラー `'Bus_RGB' does not name a type` | RGBプラットフォームヘッダ未include＋メンバ名`_panel/_bus`が基底と衝突 | `#include <lgfx/v1/platforms/esp32s3/{Panel,Bus}_RGB.hpp>`＋メンバを`_*_instance`に。同梱`LGFX_ESP32S3_RGB_ESP32-8048S043.h`を土台にする |
| **タッチ全く反応しない** | `pin_int=18`だが基板でPENIRQ未結線気味 → LovyanGFXがINT=HIGHを「未タッチ」と誤判定し全read破棄 | **`cfg.pin_int=-1`（ポーリング）** ← 最重要。SPI圧力読みで判定 |
| USB映像が来ない/ACK来ない(無反応) | `Serial.setRxBufferSize()`を`begin()`**後**に呼び失敗→RX 256Bのまま→8KBフレームで即溢れ→同期マジック落ち | `setRxBufferSize(16384)`を**`begin()`より前**に。読み出しは`readBytes`でまとめ読み |
| 「映像が映らない」 | 実は映っていた。**ストリーム終了後に見ていた**（旧FWは無信号で全消し） | 改良FWは**最後のフレームを残し**"NO SIGNAL"バッジのみ。連続配信して**動きで**確認 |
| RGBで赤青が逆 | ライブラリのカラーオーダ | `pin_d0..4`(B)と`pin_d11..15`(R)を入替（本機はデフォルトで正常） |
| RDKでポート取り違え | S3が2枚（目＋表示） | §8のVID/PID(`1a86:7523`=表示)で厳密選別。**目基板に焼かない/流さない**。`rdk_display_flash.sh`は焼く前にポートを検証 |
| JPEGDEC化後、色化け・映像が「汚い」 | JPEGDEC出力のバイトオーダーがLovyanGFX pushImageと逆 | `jpeg.setPixelType(RGB565_BIG_ENDIAN)`（LITTLEだと化ける）。または LITTLE+`lcd.setSwapBytes(true)` |
| 映像の遅延が時間とともに増える | ソース(~20fps)>消費(~6fps)でcv2/ソケットにフレーム滞留 | `display_send.py`は**drop-to-latest**(別スレッドで最新のみ保持)で対処済 |
| 稼働中にUSB断で停止 | `ser.write`が例外で落ちる | `display_send.py`は切断検知→ポート再解決(auto)→再オープンで**自動再接続**する |

---

## 13. 出典（一次情報）

**基板/表示/タッチ:** rzeldent `platformio-espressif32-sunton`(`esp32-4827S043R.json`) · Arduino_GFX Discussion #587 · LovyanGFX同梱`LGFX_ESP32S3_RGB_ESP32-8048S043.h` / issues #304 #374 #384 · esp3d.io Sunton-43-4827 · openHASP sunton/esp32-4827s043 · espboards.dev cyd-esp32-4827s043。
**USB伝送:** CH340データシート(max 2Mbps) · atomic14(ESP32-S3 USB/JPEG) · esp-cpp/camera-display · bitbank2/JPEGDEC。
**一体型MCU:** M5Stack CoreS3 docs · ESP32-S3-EYE(esp-who) · ESP32-P4-Function-EV(ESP-IDF JPEG API: 640×480@307fps) · Sipeed MaixCAM-Pro · LilyGo T-Camera-Plus-S3。
(詳細URLは調査ジャーナル参照)

---

*この資料は実機検証＋Web一次調査から起こした。矛盾を見つけたら firmware/実機 を正とし本書を直すこと。*

---

## 派生: ESP32-1732S019 (1.9" 170x320, タッチ無し) にも対応

同じファーム/プロトコルで **Sunton ESP32-1732S019** でも動く(実機確認済み、~13fps)。
SPIパネルなので **GPIOが約20本ヘッダに出ている**のが利点(目のGC9A01やサーボの増設向き)。
タッチ非搭載のため言語ボタン/くすぐったい反応はこの基板では無し。

```bash
# ビルド&書き込み (USBは同じCH340。このWindows機ではCOM7)
pio run -e esp32-1732S019 -t upload --upload-port COM7

# 送信 (PC/RDKどちらからでも。ボタン無し・小画面向け帯サイズに自動調整)
python tools/display_send.py --port COM7 --width 320 --height 170 --no-button \
  --source mjpeg:http://192.168.128.10:8080/stream
```

- パネル定義: `firmware/corosuke_display/src/LGFX_ESP32_1732S019.h`
  (ST7789 / SCLK=12 MOSI=13 DC=11 CS=10 RST=1 BL=14 / offset_x=35 / invert / setRotation(1)で横長)
- `main.cpp` は `-DBOARD_1732S019` でボード切替(4827S043と共通ソース)

---

## コンボ構成: 1732S019に目(GC9A01×2)+腕サーボを統合する

devkitの目基板(corosuke_eyes)を**ESP32-1732S019一枚に置き換えられる**構成。
ファーム = `esp32-1732S019-combo` env(お腹映像+目+サーボ+撫でを1チップで実行)。
コマンド体系はdevkit目基板と同一(emo/gaze/blink/wink/idle/arm)なので、**どちらを挿しても
RDK側は無設定で動く**(モニタが全コマンドを/eyecmdにミラーし、display_send.pyが
「A5 5B|len|テキスト」フレームでUSB転送。devkit側はttyACM直結のまま)。

### ヘッダピン配置(純正回路図V1.0で確認済み)

背面に12ピンパッド列×2(P1=左/P2=右、ピンヘッダは要はんだ付け)。

**共有バス配線(現在の採用)**: SCLK/MOSI/DC/RST を2枚へY分岐、CSのみ個別。
IO4/5/6(SCLK/MOSI/DC)は**P1の連続3パッド**なので、市販の**サーボ用Yハーネス
(2.54mm 3ピン 1→2分岐)1本**でまとめて分岐できる。RSTはもう1本のY(または1ピンY)。

| P1(上から) | GPIO | 割当 | | P2(上から) | GPIO | 割当 |
|---|---|---|---|---|---|---|
| P1-1 | IO20 | (予備・native USB D+) | | P2-1 | 5V | ⚠1N5819経由≒4.6V/1A |
| P1-2 | IO19 | (予備・native USB D-) | | P2-2 | GND | サーボGND共通化に |
| P1-3 | IO18 | 空き | | P2-3 | IO21 | 空き |
| P1-4 | IO17 | 空き | | P2-4 | IO47 | 空き |
| P1-5 | IO16 | **目CS右** | | P2-5 | IO48 | 空き |
| P1-6 | IO15 | **目CS左** | | P2-6 | IO45 | ⚠使用禁止(strapping) |
| P1-7 | IO7 | **目RST(共有Y分岐)** | | P2-7 | IO38 | 空き |
| P1-8 | IO6 | **目DC(共有Y分岐)** | | P2-8 | IO39 | 空き |
| P1-9 | IO5 | **目MOSI(共有Y分岐)** | | P2-9 | IO40 | 空き |
| P1-10 | IO4 | **目SCLK(共有Y分岐)** | | P2-10 | IO41 | **サーボ左** |
| P1-11 | 3V3 | 目VCC(2枚とも) | | P2-11 | IO42 | **サーボ右** |
| P1-12 | GND | 目GND | | P2-12 | IO2 | 撫でタッチ(T2, 任意) |

- **P1列だけで目の配線が電源込みで完結**。CSだけ左右別(IO15/IO16)、他はY分岐で共通。
- **独立配線(Y分岐なし・点対点)にも切替可能**: platformio.iniの`EYER_*`を
  IO38/39/48/47/21(P2列)へ変えて焼き直すだけ。SCLK/MOSIはGPIOマトリクスの
  「1出力信号→複数パッド複製」(`mirrorSpi3Bus()`)で左右両ピンに同時出力される。
- サーボのIO41/42はJTAGデフォルト=ブート時に信号が出ず起動ピクつきなし。
- ⚠ **サーボの電源(赤/茶)は必ず外部5Vから**。基板の5VピンはSG90のストール電流に耐えない。
  外部5VのGNDは P2-2(GND) と必ず共通化。信号線(橙)は3.3Vロジック直結でOK。
- 撫でタッチを使う時: 導電パッド/銅箔をIO2へ→ platformio.iniの `-DPET_TOUCH_PIN=-1` を `=2` に。

### 切り替え運用
- **devkit目基板に戻す**: 1732S019を抜いてdevkitをUSBへ(モニタがttyACM/CH343を自動検出)。
- **コンボに切り替え**: `pio run -e esp32-1732S019-combo -t upload` して1732S019をRDKへ。
  表示専用に戻すなら `esp32-1732S019` envを焼き直すだけ。
- 疎通確認: `curl 'http://<board>:8080/eye?raw=ping'` → display_send.log に `pong`。

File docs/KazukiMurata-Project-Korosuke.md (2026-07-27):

# Korosuke (コロ助) — Animatronic AI Robot

- **Participant:** Kazuki Murata — GitHub: [@gurimaruking](https://github.com/gurimaruking) (uecken)
- **Stage completed:** 3 (Launch)
- **Repository:** https://github.com/gurimaruking/corosuke-robot
- **Stage 3 showcase:** https://github.com/gurimaruking/corosuke-robot/blob/main/STAGE3.md
- **Design proposal (Stage 2):** https://github.com/gurimaruking/corosuke-robot/blob/main/PROPOSAL.md
- **Roadmap:** https://github.com/gurimaruking/corosuke-robot/blob/main/ROADMAP.md
- **Demo video (3–7 min):** https://youtu.be/NJwj6Iazd20
- **Community post (Stage 2):** https://discord.com/channels/1300358874280230994/1508433443648700516/1523261786034540704

## Summary

Korosuke (コロ助) is a samurai-robot character from the classic anime *Kiteretsu
Daihyakka*. This project rebuilds him as a real animatronic whose brain is a
**D-Robotics RDK X5** — using the 10 TOPS BPU for vision, ROS 2 for motion, and an
LLM voice so he speaks in his trademark "…nari" style.

For Stage 1 I took the RDK X5 from an empty board to a running on-device AI robot
brain. I flashed RDK OS 3.5.0, brought the board onto Wi-Fi, set up key-based SSH,
registered it in RDK Studio, and verified the BPU. I then drove a USB camera
(`/dev/video0`, UVC) and ran **YOLO11-nano object detection on the BPU** against a
live camera feed — detecting people and workspace objects at ~8.3 FPS end-to-end.

Along the way I hit a real thermal problem (66 °C passive) and solved it with a
40 mm fan, then designed and open-sourced the **first 3D-printable RDK X5 case**
(parametric OpenSCAD, four lids incl. a fan mount) as a contribution back to the
community.

## Technical Highlights

- **Board / compute:** RDK X5 8GB (Sunrise X5, 10 TOPS BPU), Ubuntu 22.04 / RDK OS 3.5.0, aarch64.
- **Sensor:** UVC USB camera via V4L2 (`uvcvideo`, `/dev/video0`), 640×480 MJPG, OpenCV capture.
- **AI model:** `yolo11n_detect_bayese_640x640_nv12` (YOLO11-nano, Bayes-e quantized) on **BPU core 0** via `hbm_runtime.HB_HBMRuntime`; NV12 pre-process + on-device NMS.
- **Performance:** ~8.3 FPS live (capture+decode+inference+draw); capture/decode-bound, BPU has headroom. Static-image inference ~3 s incl. model load.
- **Thermals:** 5 V 40 mm fan off the 40-pin header (pin 4/6) → idle 66 °C → ~45–49 °C, validated by `hrut_somstatus`.
- **Open-source byproduct:** [rdk-x5-modular-case](https://github.com/gurimaruking/rdk-x5-modular-case) — first community 3D-printable RDK X5 case, CC BY 4.0.
- **Next (Stage 2+):** GC9A01 eye displays reacting to detections, "…nari" LLM voice, bipedal QDD-motor motion.

## Stage 2 — Build (System Design)

For Stage 2 I turned the proven Stage-1 brain into a full **intelligent-robot design**.
The complete proposal is in [PROPOSAL.md](https://github.com/gurimaruking/corosuke-robot/blob/main/PROPOSAL.md); highlights:

- **Concept & measurable goals** — Korosuke *sees → turns → greets → emotes → gestures*, all on-device. Acceptance criteria are quantified (e.g. G1: ≥10 FPS on BPU, detection→action <150 ms; G3: wake→speech <3.0 s), grounded in Stage-1 measurements.
- **AI architecture** — a **ROS 2 graph** with the RDK X5 as the single cognitive core: `vision_node` (BPU YOLO11 + face) → `ai_brain_node` → `dialogue_node` (LLM + "…nari" persona) → `voice_node` (TTS) / `expression_node` (eyes) / `motion_node`, bridged over UART to ESP32 sub-controllers. Includes system flow + node-graph Mermaid diagrams and a **BPU/CPU-core compute-allocation table**.
- **The key pivot** — the pre-challenge design (3× ESP32 + a home server doing the AI) is re-wired so the RDK X5 owns cognition and the ESP32s become dumb real-time actuator drivers. This is *re-wiring, not re-inventing* — most subsystems already exist.
- **Engineering plan** — [BOM](https://github.com/gurimaruking/corosuke-robot/blob/main/PROPOSAL.md#31-bill-of-materials-summary), ROS 2 workspace layout, a week-by-week [ROADMAP.md](https://github.com/gurimaruking/corosuke-robot/blob/main/ROADMAP.md) through the 7/15 demo, and a top-8 **risk table** with mitigations and pivot triggers (bipedal locomotion is explicitly a decoupled stretch, never on the MVP critical path).

Progress already banked toward Stage 3: the full body has been **redesigned for color-split 3D printing**, and the **eye coprocessor is alive** — 2× GC9A01 round LCDs driven by an ESP32-S3 (LovyanGFX) with emotion/gaze/blink commands over UART.

## Stage 3 — Launch (Fully On-Device Interactive Robot)

Stage 3 delivered the working, packaged robot — a ~46 cm Korosuke that **wakes up and
greets you, sees and tracks you, listens, thinks, talks back, smiles, ponders, reacts to
gestures, waves its arms, and shuts itself down safely — 100 %
on-device, no cloud, no dev PC at runtime.** Full showcase (benchmarks, Mermaid
architecture, known-issues / failure-recovery, requirement-coverage table):
**[STAGE3.md](https://github.com/gurimaruking/corosuke-robot/blob/main/STAGE3.md)**.

Highlights:
- **On-device AI pipeline** — BPU YOLO11n-pose (~19.5 FPS) for perception; CPU sherpa-onnx
  STT (RTF 0.44) → TinySwallow-1.5B LLM (llama.cpp) → Open JTalk TTS for dialogue. **The
  BPU does perception, the CPU does language** — I verified from D-Robotics' *own* X5
  packages that the X5 BPU **cannot** accelerate an LLM (an S100/Nash-only feature), so
  this split is the correct architecture, not a shortfall.
- **Two integrations of one on-device pipeline** — a **ROS 2 graph** (6 nodes + custom
  `FacePose`/`EyeCmd` messages, `ros2 launch korosuke_nodes korosuke.launch.py`) whose
  `dialogue_node`/`voice_node` run the **same on-device stack as the monolith (TinySwallow
  via llama.cpp + Open JTalk, no cloud)**, and a low-latency monolithic `korosuke-monitor`
  service (adds the web dashboard, audio DSP and 8-state eyes). All live testing and the
  demo video use the monolith; in the ROS graph the vision→eyes path is HW-verified and the
  full dialogue graph is code-complete (end-to-end board run pending) — see STAGE3 §5.1.
- **Custom kernel work to miniaturize audio** — the oversized speakers were replaced by a
  φ50 driver on a **MAX98357A I2S amp**, for which I built an **out-of-tree ALSA codec
  driver + device-tree overlay** the vendor kernel didn't ship, plus a playback DSP so the
  small speaker is loud without clipping.
- **Ships like a product** — power-on auto-start (systemd), a physical **safe-shutdown
  button** (goodnight voice → ✕✕ "safe-to-unplug" eyes), a self-healing audio card, a
  static maintenance IP, and expressive **smile / thinking / ✕✕** eyes.
- **Multi-task on one board** — BPU vision + CPU STT/LLM/TTS run concurrently at
  **≈50 °C** (< 60 °C target) even with the LLM pinning ~600 % CPU.

Engineering investigations produced along the way (all in `docs/`):
[why BPU-LLM is S100-only](https://github.com/gurimaruking/corosuke-robot/blob/main/docs/rdk_x5_bpu_llm.md),
the [I2S amp build](https://github.com/gurimaruking/corosuke-robot/blob/main/docs/rdk_x5_40pin_i2s_max98357a.md),
and a [power/USB brown-out troubleshooting guide](https://github.com/gurimaruking/corosuke-robot/blob/main/docs/power_usb_troubleshooting.md).

## Links & Evidence

- Stage 1 write-up (commands + dependencies): https://github.com/gurimaruking/corosuke-robot/blob/main/STAGE1.md
- Screenshot A — RDK Studio connected to the board (SSH connected, live remote desktop): https://github.com/gurimaruking/corosuke-robot/blob/main/docs/stage1_evidence/A_flash_ssh.png
- Screenshot B — camera preview: https://github.com/gurimaruking/corosuke-robot/blob/main/docs/stage1_evidence/B_camera_preview.jpg
- Screenshot C — live YOLO11 detection on-device: https://github.com/gurimaruking/corosuke-robot/blob/main/docs/stage1_evidence/C_yolo_live_detection.jpg
- Live demo (GIF): https://github.com/gurimaruking/corosuke-robot/blob/main/docs/stage1_evidence/D_yolo_live_demo.gif
- Open-source case: https://github.com/gurimaruking/rdk-x5-modular-case

---

I agree that this showcase document may be used by the Robotics Dream Keeper Challenge organizers as described in the official README (promotion, judging, and archives).

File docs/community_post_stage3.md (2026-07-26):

# Community post — Stage 3 (Launch) 告知ドラフト

> そのままDiscord/フォーラムに貼れる下書き。`<YouTube link>` を差し替えてください。
> 短縮版(Discord向け)と長め版(フォーラム/Note向け)の2つを用意。

---

## 短縮版（Discord / X 向け）

🤖✨ **Project Korosuke — Stage 3 (Launch) done!**

🙌 本来は店長が担当する予定でしたが、イベントで大忙しだったので、私が代わりに仕上げさせてもらいました！

コロ助（キテレツ大百科）を **RDK X5** で本物のアニマトロニクスにしました。**100%オンデバイス・クラウド無し**で：

👀 見る（BPU YOLO11-pose ~19.5FPS）→ 👂 聞く（sherpa-onnx **SenseVoice**・日英）→ 🧠 考える（TinySwallow-1.5B on CPU、考え中は目がくるくる）→ 🗣 話す（Open JTalk / espeak-ng、「〜ナリ」）→ 😊 笑う → 🙌 手を振る → 🌙 ボタンで安全終了（おやすみ→✕✕の目）

🔧 見どころ：スピーカー小型化のために **MAX98357A I2Sアンプ用のカーネルドライバを自作**（vendorカーネルに無い）。**日本語↔英語をワンタッチ切替**（STT・LLM・音声・Web UI）。BPUでLLMは回せない（S100専用）ことも公式パッケージから検証。

🎥 デモ： `<YouTube link>`
💻 リポジトリ： https://github.com/gurimaruking/corosuke-robot
📄 ショーケース： https://github.com/gurimaruking/corosuke-robot/blob/main/STAGE3.md

#RDKX5 #DRobotics #ROS2 #EdgeAI

---

## 長め版（フォーラム / Note / Hackster 向け）

### Korosuke, the fully on-device animatronic — Stage 3 launch 🚀

🙌 *Our shop's manager was set to lead this one, but got swamped with an event — so I got to finish it on their behalf!*

I rebuilt **Korosuke (コロ助)** from *Kiteretsu Daihyakka* as a ~46 cm desktop robot whose
brain is a single **D-Robotics RDK X5**. Everything — vision, speech-to-text, LLM dialogue,
text-to-speech, expression, gesture and actuation — runs **on-device, no cloud, no
dev PC at runtime**.

**What it does:** power it on and it wakes up and greets you ("おはようナリ！"), tracks you
with BPU YOLO11-pose, listens, thinks (the eyes do a "考え中" animation while the on-device
LLM ponders), talks back in a pitched "…ナリ" voice **in Japanese or English**, smiles,
reacts to gestures, waves its rope-pulled arms, and shuts itself down safely on a button
press (goodnight voice → ✕✕ "safe-to-unplug" eyes).

**The engineering story I'm proud of:**
- **BPU does perception, CPU does language.** I verified from D-Robotics' *own* X5 packages
  that the X5 BPU can't accelerate an LLM (that's an S100/Nash feature) — so putting
  perception on the BPU and dialogue on the 8× A55 CPU is the *correct* design.
- **Custom kernel work to shrink the speaker.** No MAX98357A codec driver ships in the RDK
  kernel, so I built an **out-of-tree ALSA codec driver + device-tree overlay** and a
  playback DSP so a tiny φ50 speaker is loud without clipping.
- **Bilingual, on the fly.** One switch flips STT, the LLM persona, the voice *and* the web
  dashboard between **Japanese and English** — all still on-device.
- **Ships like a product:** systemd auto-start on power-on, a physical safe-shutdown, a
  self-healing audio card, and a tabbed web dashboard to tune everything live.

Benchmarks (all measured on the board): YOLO11n-pose ~19.5 FPS, STT RTF 0.44, LLM
1.5–3.3 tok/s, and the whole stack runs at ≈50 °C (< 60 °C) even with the LLM pinning
~600 % CPU.

🎥 **Demo video:** https://youtu.be/NJwj6Iazd20
💻 **Repo:** https://github.com/gurimaruking/corosuke-robot
📄 **Full showcase & benchmarks:** https://github.com/gurimaruking/corosuke-robot/blob/main/STAGE3.md
🧩 **Design:** [PROPOSAL.md](https://github.com/gurimaruking/corosuke-robot/blob/main/PROPOSAL.md) · 🗺 [ROADMAP.md](https://github.com/gurimaruking/corosuke-robot/blob/main/ROADMAP.md)

Built for the **D-Robotics Robotics Dream Keeper Challenge**. Fan-made, non-commercial
tribute — character © Fujiko F. Fujio.

*「ワガハイはコロ助ナリ！」* 🤖

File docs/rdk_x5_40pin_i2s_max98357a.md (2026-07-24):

# RDK X5 40ピン I2S 配線 & MAX98357A 接続

コロ助のスピーカーを小型化するため、I2Sデジタルアンプ **MAX98357A** を
RDK X5 の 40ピンに直結する。既存のオンボード ES8326（内部 i2s0）はそのまま残し、
MAX98357A は **40ピンに出ている I2S1（`dw_i2s1`）** に繋いで独立した再生カードにする。

## 出典（公式ピンアサイン）
- D-Robotics 公式: [RDK X5 40pin define](https://developer.d-robotics.cc/rdk_doc/en/Basic_Application/01_40pin_user_sample/40pin_define)
- 実機の `/usr/local/lib/python3.10/dist-packages/Hobot/GPIO/gpio_pin_data.py` とも突き合わせ済み（一致）。

## 40ピン I2S1 割り当て（Board Pin = 物理ピン番号）

| Board Pin | 信号 (CVM Func) | X5 Pin Index | 用途 | MAX98357A |
|---|---|---|---|---|
| **2**（or 4） | VDD_5V | — | 電源 | **VIN** |
| **6**（or 9/14/20/25/30/34/39） | GND | — | GND | **GND** |
| **7** | I2S1_MCLK | 420 | マスタクロック | 不要（内部PLL） |
| **12** | I2S1_BCLK | 421 | ビットクロック | **BCLK** |
| **35** | I2S1_LRCK (I2S1 WS) | 422 | LR/ワードセレクト | **LRC** |
| **38** | I2S1_SDIN (DI) | 423 | データ入力（→ボード, マイク用） | 不要 |
| **40** | I2S1_SDOUT (DO) | 424 | データ出力（ボード→アンプ） | **DIN** |

> 40ピンは Raspberry Pi 互換の 2×20。**左列=奇数(1,3,…39)／右列=偶数(2,4,…40)**、
> ピン1が基板内側の角。**必須は 5V / GND / DIN / BCLK / LRC の5本のみ**（MCLK・SDINは未使用）。

```
 (1) 3V3        5V   (2)   ← VIN
 (5) ...        GND  (6)   ← GND
(11) ...   I2S1_BCLK (12)  ← BCLK
(35) I2S1_LRCK ...   (36)  ← LRC
(39) GND   I2S1_SDOUT(40)  ← DIN（右下の角）
```

## MAX98357A の GAIN / SD 端子
- **GAIN**: 未接続=9dB（既定）。GNDに落とすと12dB。抵抗で3/6/15dBも可だが小型8Ωなら未接続でよい。
- **SD**（シャットダウン兼 L/R/mono 選択）: 未接続=アンプON・(L+R)/2 mono 相当。
  ソフトからミュート/省電力したい場合のみ空きGPIOへ（HIGH=再生, 0V=停止）。今回は未接続。

## スピーカー
- **採用: 秋月 WYGD50D-8-03**（8Ω・φ50mm・厚18.5mm・定格0.2W/max0.4W・F0 550Hz・防磁）
  = [g109012](https://akizukidenshi.com/catalog/g/g109012/)
- 経緯: 当初 MSI28-12R（φ28・g112587）を採用したが、**音量最大で歪む**（φ28は口径が小さく
  過振幅で割れる）。実機切り分けで**律速はアンプでなくスピーカー**と判明。**φ50に交換したら
  「全然質が良くなった」**（大口径＝同音圧でコーン振幅が小さく歪み激減）。
- **注意: WYGD50Dは0.2W(max0.4W)と耐入力が低い**。MAX98357Aは8Ω/5Vで最大~1.8W出せるため、
  過大入力で破損しないよう **DSPの `peak_ceil_db` を -9dBFS(≈0.2W) に制限**して運用。
  もっと大音量が要るなら高耐入力の φ40〜50 フルレンジ(例: DXYD40-22P-4A 4Ω3W [g116025])へ。
- 接続: MAX98357A の SPK+ / SPK− に接続（無極性で可）。

## ソフト側（i2s1 再生カードの作成）
RDK カーネルには MAX98357A 専用ドライバも in-tree ダミーコーデック（spdif-dit）も無いが、
`hobot-kernel-headers` が導入済みで **out-of-tree ビルド可能**。

1. `snd-soc-max98357a`（`sound/soc/codecs/max98357a.c`, v6.1.83）を out-of-tree ビルド
   （初回のみ `sudo make -C /usr/src/linux-headers-6 modules_prepare` で `fixdep` 等を生成）。
2. DTオーバーレイ `max98357a.dtbo`（`simple-audio-card` で `dw_i2s1`(master) ↔ `maxim,max98357a`、
   `format="i2s"`, `mclk-fs=64`）を `dtc` でコンパイルし `/boot/overlays/` へ配置。
3. `/boot/config.txt` に `dtoverlay=max98357a` を追記（末尾に空行必須）して再起動。
4. `aplay -l` に card "max98357a" が出現 → `aplay -D plughw:max98357a ...` で再生確認。
5. `korosuke_monitor.py` の TTS 出力（Open JTalk → aplay）をこのカードに向ける。

ビルド成果物とオーバーレイソースは `firmware/max98357a/`（本リポジトリ）に保管。

## 音質/音量チューニング（小型SP最適化 DSP）
小型SPは「クリーンに鳴らせるピーク上限」が低く、超えるとコーン底打ちで割れる。
**実測（φ28 MSI28-12R 裸・未固定）: クリーン天井 ≈ −6dBFS**（−6までクリーン、−3から歪む）。
Open JTalk 原音のピークは約 −4.7dBFS で天井を超えるため、特に**発話冒頭が割れる**。

### 出力電力の実際（8Ω・5V・GAIN 9dB）
- **−6dBFS 天井運用時: ピーク ≈ 0.4W / 声の平均 ≈ 0.03–0.05W**
- アンプ上限(8Ω): 約 1.6W（クリップ）/ 1.8W(10%THD)、4Ωなら約 3.2W
- → **律速はアンプでなくスピーカー**（φ28 は約0.4Wで機械的に歪む）。大音量化は
  「SPをバッフル/箱に固定」＋「大口径・高耐入力SPへ交換」が本筋。

### DSP（`korosuke_monitor.py _playback()`、MAX98357A 時のみ）
1. **HPF**（既定250Hz, `hpf`）… 出せない低域を除去しコーン保護
2. **コンプレッサ+速リミッタ**（ffmpeg）… 突発ピーク（冒頭割れ）を均す
3. **ピーク正規化**（audioop）… ピークを `peak_ceil_db`(既定−6dBFS)×音量に固定
   → クリップせず体感音量を最大化。実測で RMS +1〜2dB、冒頭割れ解消。

Web: 「🎛 小型SP最適化」ON/OFF・「クリーン上限」スライダー(`peak_ceil_db`)。
**SPを固定/交換して天井が上がったら `peak_ceil_db` を上げる**と更に大音量化できる。
GAIN 端子のハードゲイン(未接続=9dB / GND=12dB)とは別系統で併用可。

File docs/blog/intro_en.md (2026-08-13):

# I am Korosuke! — An era when anyone can build a robot

<p>
D-Robotics
Robotics Dream Keeper Challenge
</p>

> D-Robotics **Robotics Dream Keeper Challenge** participation story (English version).
> 日本語版はこちら → [intro_ja.md](intro_ja.md) · Full technical details → [STAGE3.md](../../STAGE3.md)

## Table of contents
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

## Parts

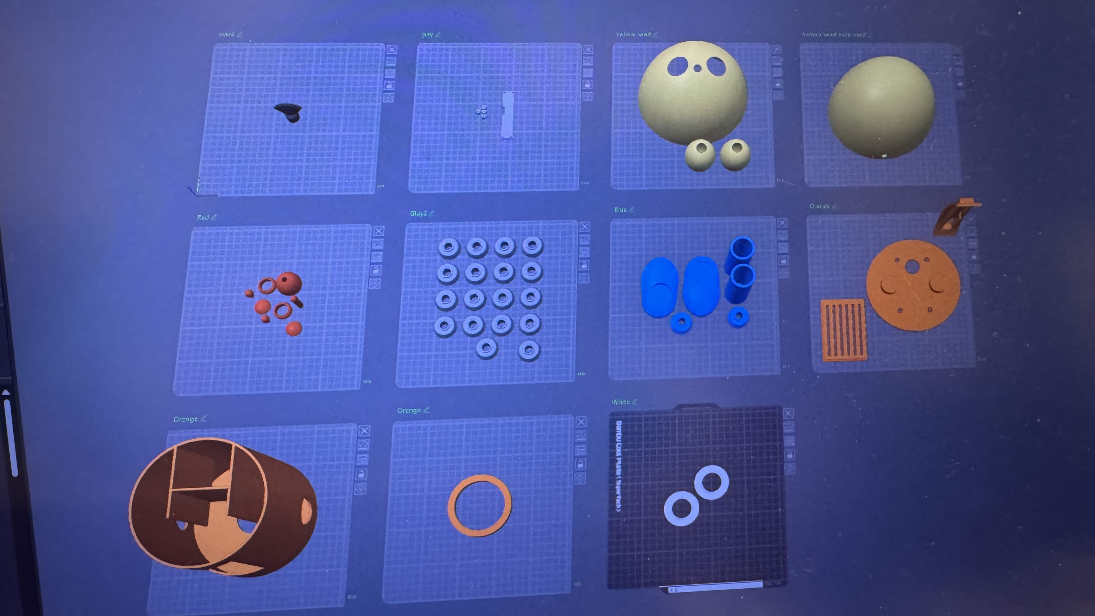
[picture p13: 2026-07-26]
docs/photo/korosuke_3Dprint_parts.jpg

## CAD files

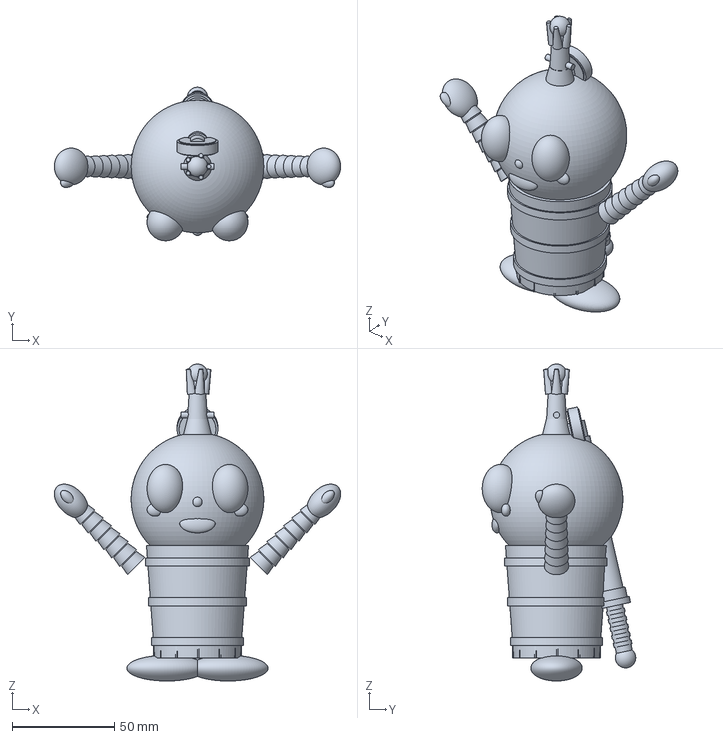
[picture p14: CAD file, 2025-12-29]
hardware/3d_models/export/3mf/korosuke_accurate_full.3mf
140.2 x 75.2 x 155.2 mm

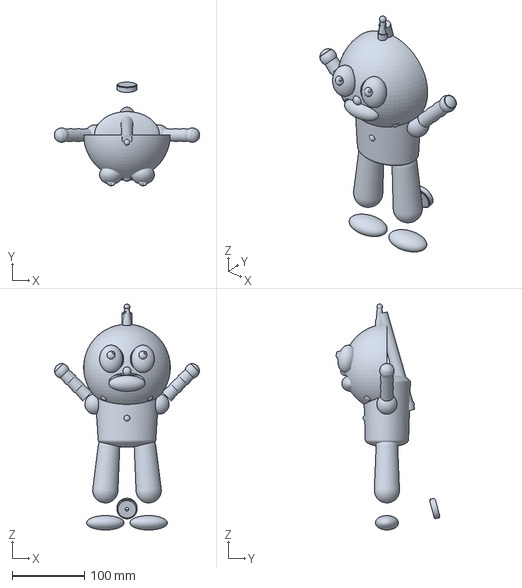
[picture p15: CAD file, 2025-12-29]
hardware/3d_models/export/3mf/corosuke_full.3mf
201.2 x 143.7 x 313.0 mm

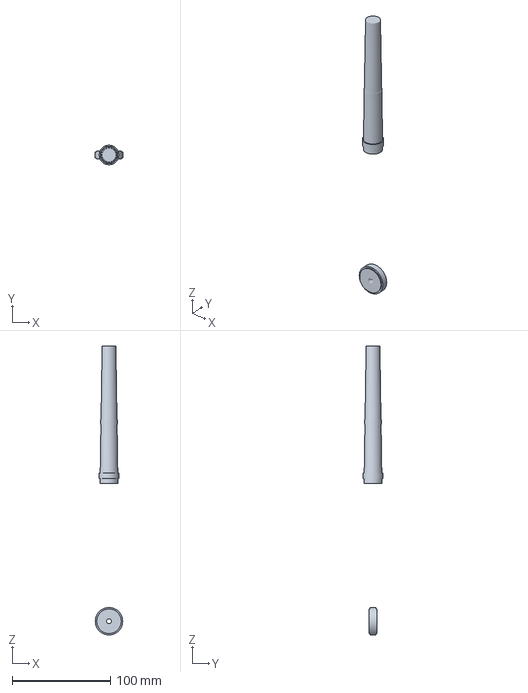
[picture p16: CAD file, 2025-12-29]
hardware/3d_models/export/3mf/sword_full.3mf
28.0 x 20.0 x 294.0 mm

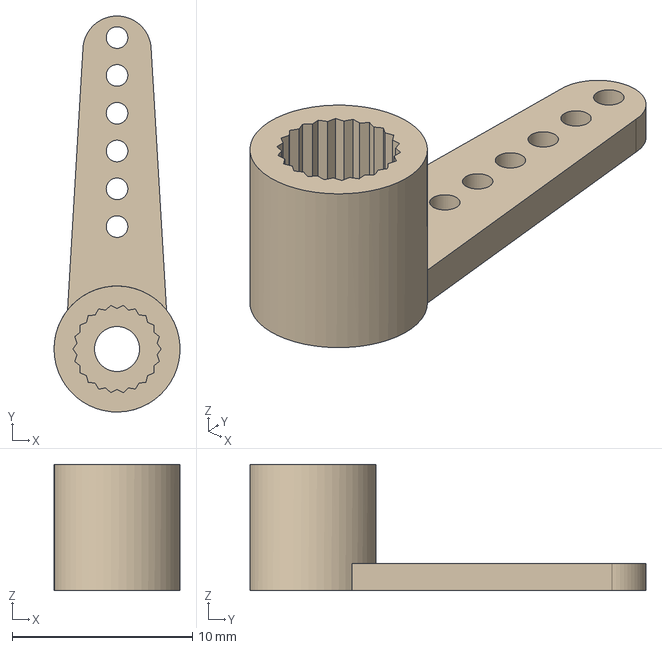
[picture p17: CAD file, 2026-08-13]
hardware/3d_models/korosuke_print/sg90-servomotor-arms-1.snapshot.33/SG90_Arm_01_Custom/SG90_Arm_01_Custom.step
7.00 x 22.0 x 7.00 mm

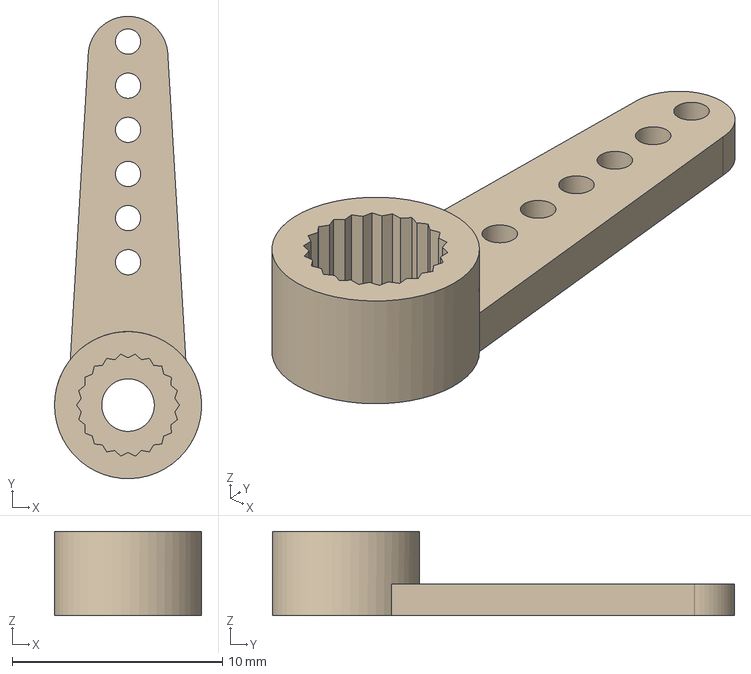
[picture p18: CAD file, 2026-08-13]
hardware/3d_models/korosuke_print/sg90-servomotor-arms-1.snapshot.33/SG90_Arm_02_Custom/SG90_Arm_02_Custom.step
7.00 x 22.0 x 4.00 mm

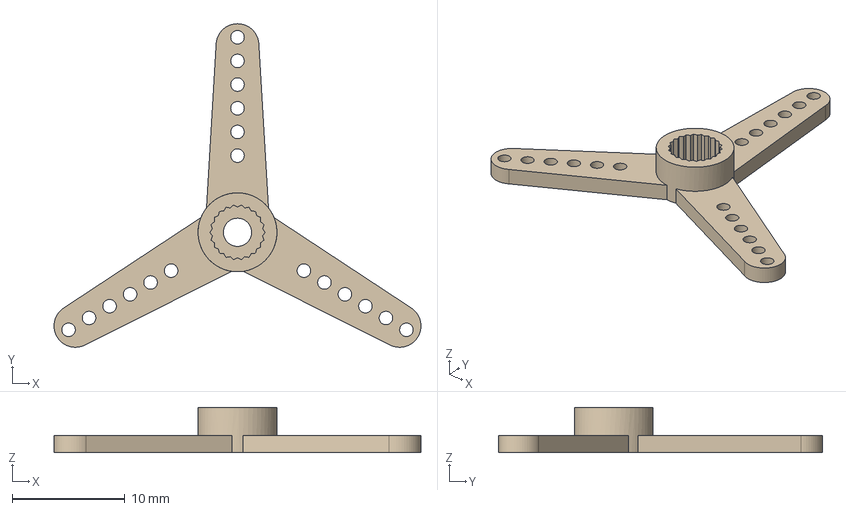
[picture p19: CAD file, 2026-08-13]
hardware/3d_models/korosuke_print/sg90-servomotor-arms-1.snapshot.33/SG90_Arm_03_Custom/SG90_Arm_03_Custom.step
32.5 x 28.7 x 4.00 mm

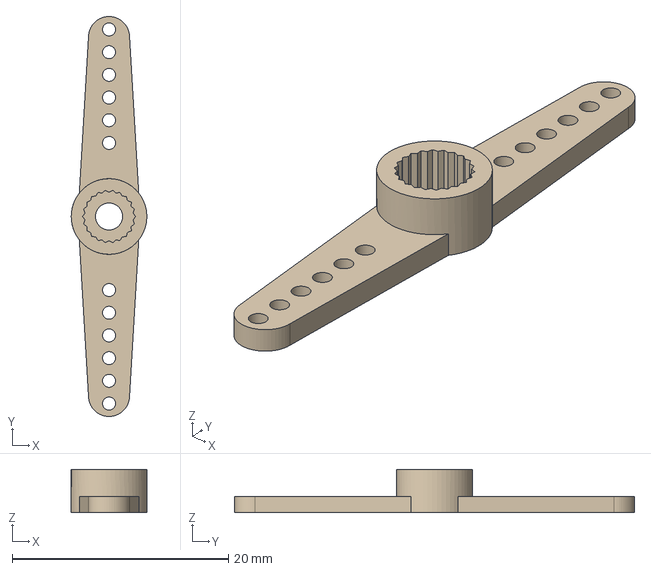
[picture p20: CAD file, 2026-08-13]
hardware/3d_models/korosuke_print/sg90-servomotor-arms-1.snapshot.33/SG90_Arm_04_Custom/SG90_Arm_04_Custom.step
6.99 x 37.0 x 4.00 mm

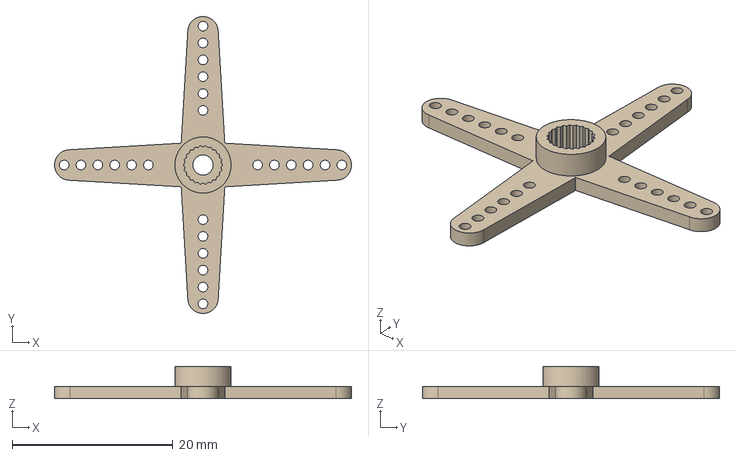
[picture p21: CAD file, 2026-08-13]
hardware/3d_models/korosuke_print/sg90-servomotor-arms-1.snapshot.33/SG90_Arm_05_Custom/SG90_Arm_05_Custom.step
37.0 x 37.0 x 4.00 mm

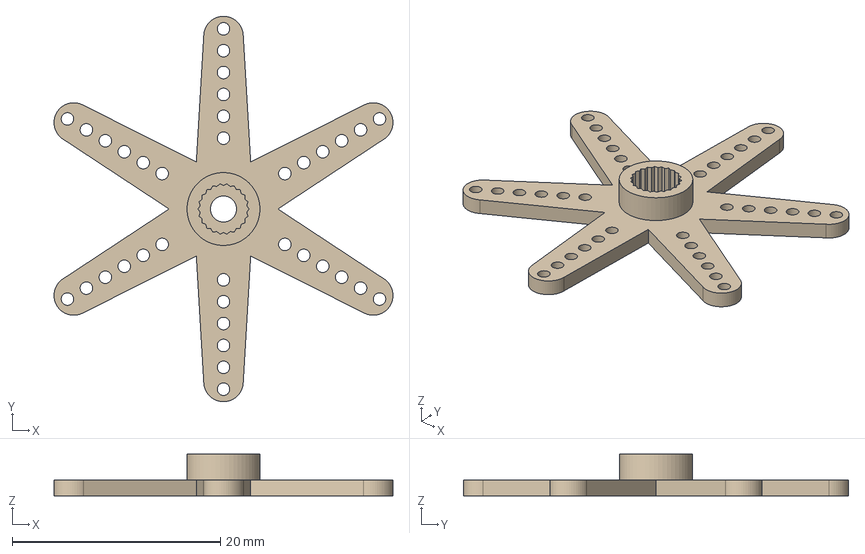
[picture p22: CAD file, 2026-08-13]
hardware/3d_models/korosuke_print/sg90-servomotor-arms-1.snapshot.33/SG90_Arm_06_Custom/SG90_Arm_06_Custom.step
32.5 x 37.0 x 4.00 mm

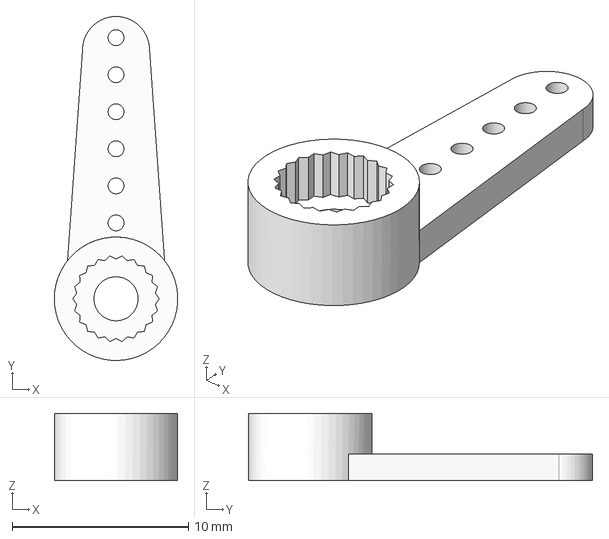
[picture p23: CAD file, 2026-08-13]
hardware/3d_models/korosuke_print/sg90-servomotor-arms-1.snapshot.33/SG90_Arm_Original/SG90_Arm_Original.step
7.00 x 19.5 x 3.80 mm

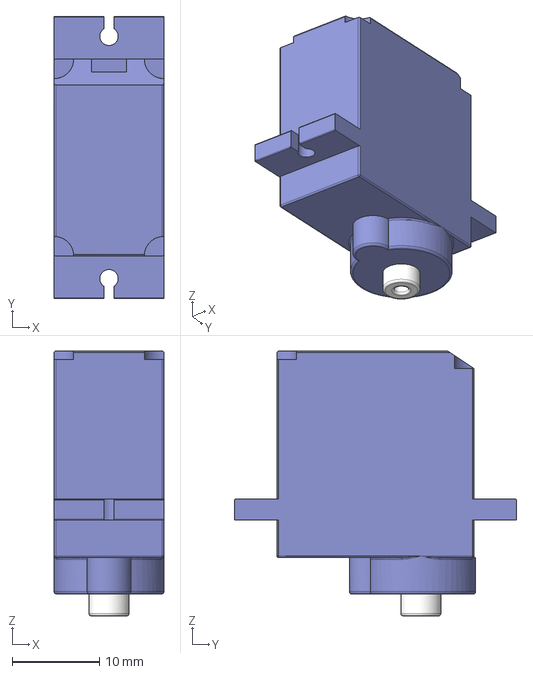
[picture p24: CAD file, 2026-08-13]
hardware/3d_models/korosuke_print/sg90-servomotor-arms-1.snapshot.33/SG90_Model_A/SG90_Model_A.step
12.6 x 32.4 x 30.4 mm

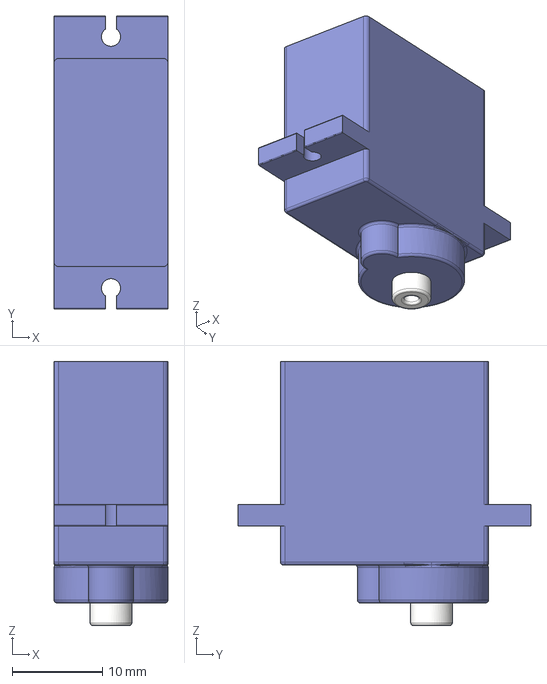
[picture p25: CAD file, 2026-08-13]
hardware/3d_models/korosuke_print/sg90-servomotor-arms-1.snapshot.33/SG90_Model_B/SG90_Model_B.step
12.6 x 32.4 x 29.2 mm

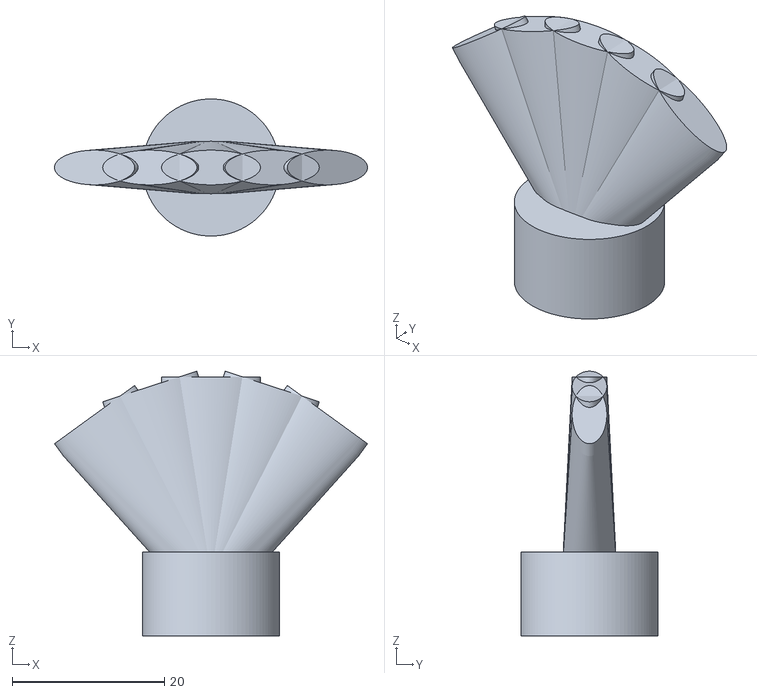
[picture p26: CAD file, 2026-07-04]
hardware/3d_models/korosuke_print/stl/black/topknot_fan_x1.stl
41.1 x 18.0 x 34.7

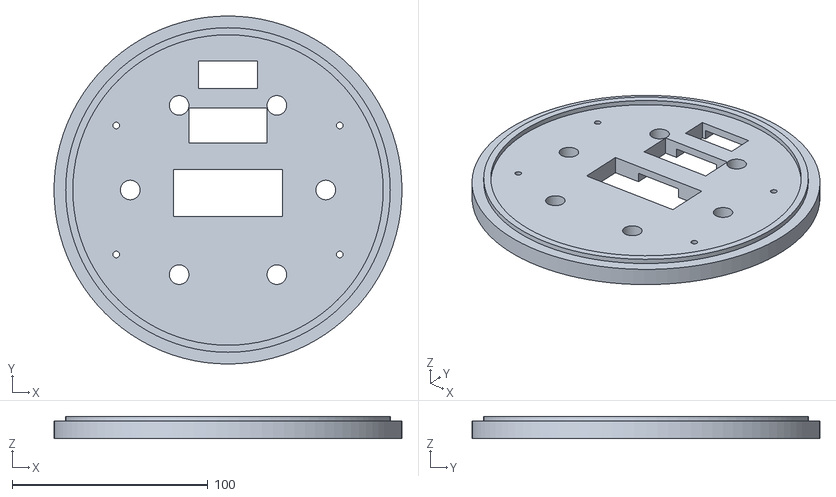
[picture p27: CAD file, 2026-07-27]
hardware/3d_models/korosuke_print/stl/gray/foot_base_v2_x1.stl
178.0 x 178.0 x 11.5

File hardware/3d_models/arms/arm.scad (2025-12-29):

/**
 * コロ助ロボット - 腕
 * Corosuke Robot - Arm
 *
 * コロ助の腕（左右共通・ミラー使用）
 * - 肩関節（上下）
 * - 肘関節（曲げ）
 * - 手（固定）
 */

// =============================================================================
// パラメータ
// =============================================================================

// 上腕
upper_arm_length = 50;
upper_arm_diameter = 25;

// 前腕
lower_arm_length = 45;
lower_arm_diameter = 22;

// 手
hand_width = 30;
hand_height = 25;
hand_depth = 15;
finger_length = 20;
finger_diameter = 8;

// 関節
joint_diameter = 20;
joint_width = 15;

// サーボ
servo_width = 12.5;
servo_height = 22.5;
servo_depth = 23;

// =============================================================================
// モジュール: 上腕
// =============================================================================
module upper_arm() {
    difference() {
        union() {
            // メインシリンダー
            cylinder(h = upper_arm_length, d = upper_arm_diameter, $fn = 32);

            // 肩関節部
            translate([0, 0, upper_arm_length])
                sphere(d = joint_diameter + 5, $fn = 32);
        }

        // サーボスペース
        translate([0, 0, upper_arm_length/2])
            cube([servo_width + 1, servo_depth + 1, servo_height + 1], center = true);

        // 肘関節穴
        translate([0, 0, -1])
            cylinder(h = 10, d = 6, $fn = 32);
    }
}

// =============================================================================
// モジュール: 肩関節
// =============================================================================
module shoulder_joint() {
    difference() {
        union() {
            // 関節球
            sphere(d = joint_diameter, $fn = 32);

            // 取り付け部
            translate([0, 0, joint_diameter/2])
                cylinder(h = 15, d = joint_diameter - 5, $fn = 32);
        }

        // シャフト穴
        cylinder(h = joint_diameter * 2, d = 6, center = true, $fn = 32);

        // サーボホーン取り付け
        translate([0, 0, joint_diameter/2 + 10])
            cylinder(h = 10, d = 8, $fn = 32);
    }
}

// =============================================================================
// モジュール: 前腕
// =============================================================================
module lower_arm() {
    difference() {
        union() {
            // メインシリンダー
            cylinder(h = lower_arm_length, d = lower_arm_diameter, $fn = 32);

            // 肘関節部
            translate([0, 0, lower_arm_length])
                rotate([90, 0, 0])
                    cylinder(h = joint_width, d = joint_diameter, center = true, $fn = 32);
        }

        // 手首接続穴
        translate([0, 0, -1])
            cylinder(h = 15, d = 8, $fn = 32);

        // 肘関節軸穴
        translate([0, 0, lower_arm_length])
            rotate([90, 0, 0])
                cylinder(h = joint_width + 10, d = 3, center = true, $fn = 32);
    }
}

// =============================================================================
// モジュール: 肘関節
// =============================================================================
module elbow_joint() {
    difference() {
        // 関節ブロック
        hull() {
            rotate([90, 0, 0])
                cylinder(h = joint_width - 2, d = joint_diameter - 2, center = true, $fn = 32);

            translate([0, 0, -15])
                cylinder(h = 5, d = upper_arm_diameter - 5, $fn = 32);
        }

        // 軸穴
        rotate([90, 0, 0])
            cylinder(h = joint_width + 5, d = 3, center = true, $fn = 32);

        // サーボホーン取り付け
        rotate([90, 0, 0])
            translate([0, 0, joint_width/2 - 3])
                cylinder(h = 5, d = 8, $fn = 32);
    }
}

// =============================================================================
// モジュール: 手（簡易版）
// =============================================================================
module hand() {
    // 手のひら
    hull() {
        translate([0, 0, 0])
            sphere(d = hand_depth, $fn = 32);
        translate([0, 0, hand_height - hand_depth/2])
            resize([hand_width, hand_depth, hand_depth])
                sphere(d = hand_depth, $fn = 32);
    }

    // 指（4本まとめて）
    translate([0, 0, hand_height]) {
        for (x = [-hand_width/3, -hand_width/9, hand_width/9, hand_width/3]) {
            translate([x, 0, 0])
                finger();
        }
    }

    // 親指
    translate([hand_width/2 - 3, 0, hand_height/2])
        rotate([0, 30, 0])
            scale([0.8, 1, 0.8])
                finger();
}

// =============================================================================
// モジュール: 指
// =============================================================================
module finger() {
    // 指を3関節で表現
    union() {
        // 第1関節
        cylinder(h = finger_length * 0.4, d = finger_diameter, $fn = 16);

        // 第2関節
        translate([0, 0, finger_length * 0.4])
            rotate([10, 0, 0]) {
                cylinder(h = finger_length * 0.35, d = finger_diameter * 0.9, $fn = 16);

                // 第3関節（先端）
                translate([0, 0, finger_length * 0.35])
                    rotate([10, 0, 0])
                        cylinder(h = finger_length * 0.25, d1 = finger_diameter * 0.8, d2 = finger_diameter * 0.5, $fn = 16);
            }
    }
}

// =============================================================================
// モジュール: 完全な腕
// =============================================================================
module complete_arm(is_right = true) {
    mirror_factor = is_right ? 1 : -1;

    // 肩関節
    color("gray")
        shoulder_joint();

    // 上腕
    color("white")
        translate([0, 0, -upper_arm_length - 5])
            upper_arm();

    // 肘関節
    color("gray")
        translate([0, 0, -upper_arm_length - 10])
            elbow_joint();

    // 前腕
    color("white")
        translate([0, 0, -upper_arm_length - lower_arm_length - 20])
            lower_arm();

    // 手
    color("pink")
        translate([0, 0, -upper_arm_length - lower_arm_length - 25])
            rotate([180, 0, 0])
                hand();
}

// =============================================================================
// モジュール: 腕カバー（外装）
// =============================================================================
module arm_cover() {
    cover_thickness = 2;

    difference() {
        union() {
            // 上腕カバー
            cylinder(h = upper_arm_length - 5, d = upper_arm_diameter + cover_thickness * 2, $fn = 32);

            // 前腕カバー
            translate([0, 0, -lower_arm_length - 15])
                cylinder(h = lower_arm_length - 5, d = lower_arm_diameter + cover_thickness * 2, $fn = 32);
        }

        // 内部くり抜き
        translate([0, 0, -1])
            cylinder(h = upper_arm_length, d = upper_arm_diameter + 1, $fn = 32);

        translate([0, 0, -lower_arm_length - 16])
            cylinder(h = lower_arm_length, d = lower_arm_diameter + 1, $fn = 32);
    }
}

// =============================================================================
// 出力
// =============================================================================

// 完全な腕（右）
complete_arm(true);

// 個別パーツ出力用
// upper_arm();
// lower_arm();
// shoulder_joint();
// elbow_joint();
// hand();

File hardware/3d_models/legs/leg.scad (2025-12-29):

/**
 * コロ助ロボット - 脚
 * Corosuke Robot - Leg
 *
 * 二足歩行用の脚（左右共通・ミラー使用）
 * - 股関節（ヨー・ピッチ）
 * - 膝関節
 * - 足首関節
 * - 足（TPU製足裏）
 */

// =============================================================================
// パラメータ
// =============================================================================

// 大腿部
thigh_length = 60;
thigh_width = 35;
thigh_depth = 30;

// 下腿部
shin_length = 55;
shin_width = 30;
shin_depth = 25;

// 足
foot_length = 70;
foot_width = 45;
foot_height = 20;

// 関節
hip_joint_diameter = 30;
knee_joint_diameter = 25;
ankle_joint_diameter = 20;

// サーボ (DS3218 - 20kg)
ds3218_width = 20;
ds3218_height = 40.5;
ds3218_depth = 40;

// サーボ (MG996R)
mg996r_width = 20;
mg996r_height = 40;
mg996r_depth = 42;

// =============================================================================
// モジュール: 股関節ブロック
// =============================================================================
module hip_block() {
    difference() {
        union() {
            // メインブロック
            cube([thigh_width + 20, thigh_depth + 10, 40], center = true);

            // ヨー軸接続部（上）
            translate([0, 0, 25])
                cylinder(h = 15, d = hip_joint_diameter, $fn = 32);
        }

        // ヨー軸穴
        translate([0, 0, 20])
            cylinder(h = 25, d = 6, $fn = 32);

        // ピッチ軸サーボスペース
        translate([0, 0, -5])
            cube([ds3218_width + 1, ds3218_depth + 1, ds3218_height + 1], center = true);

        // 配線穴
        translate([thigh_width/2 + 5, 0, 0])
            cylinder(h = 50, d = 8, center = true, $fn = 32);
    }
}

// =============================================================================
// モジュール: 大腿部
// =============================================================================
module thigh() {
    difference() {
        union() {
            // メインボディ
            hull() {
                translate([0, 0, 5])
                    cube([thigh_width, thigh_depth, 10], center = true);
                translate([0, 0, thigh_length - 5])
                    cube([thigh_width - 5, thigh_depth - 5, 10], center = true);
            }

            // 股関節接続部（上）
            translate([0, 0, thigh_length])
                rotate([0, 90, 0])
                    cylinder(h = thigh_width + 10, d = hip_joint_diameter - 5, center = true, $fn = 32);

            // 膝関節接続部（下）
            rotate([0, 90, 0])
                cylinder(h = thigh_width, d = knee_joint_diameter, center = true, $fn = 32);
        }

        // 股関節軸穴
        translate([0, 0, thigh_length])
            rotate([0, 90, 0])
                cylinder(h = thigh_width + 20, d = 6, center = true, $fn = 32);

        // 膝関節軸穴
        rotate([0, 90, 0])
            cylinder(h = thigh_width + 10, d = 6, center = true, $fn = 32);

        // 内部空洞（軽量化）
        translate([0, 0, thigh_length/2])
            cube([thigh_width - 10, thigh_depth - 10, thigh_length - 30], center = true);

        // サーボスペース
        translate([0, 0, thigh_length/2 + 10])
            cube([ds3218_width + 1, ds3218_depth + 1, ds3218_height + 1], center = true);
    }
}

// =============================================================================
// モジュール: 下腿部
// =============================================================================
module shin() {
    difference() {
        union() {
            // メインボディ
            hull() {
                translate([0, 0, 5])
                    cube([shin_width, shin_depth, 10], center = true);
                translate([0, 0, shin_length - 5])
                    cube([shin_width - 5, shin_depth - 5, 10], center = true);
            }

            // 膝関節接続部（上）
            translate([0, 0, shin_length])
                rotate([0, 90, 0])
                    cylinder(h = shin_width + 5, d = knee_joint_diameter - 3, center = true, $fn = 32);

            // 足首関節接続部（下）
            rotate([0, 90, 0])
                cylinder(h = shin_width, d = ankle_joint_diameter, center = true, $fn = 32);
        }

        // 膝関節軸穴
        translate([0, 0, shin_length])
            rotate([0, 90, 0])
                cylinder(h = shin_width + 15, d = 6, center = true, $fn = 32);

        // 足首関節軸穴
        rotate([0, 90, 0])
            cylinder(h = shin_width + 10, d = 6, center = true, $fn = 32);

        // 内部空洞
        translate([0, 0, shin_length/2])
            cube([shin_width - 10, shin_depth - 10, shin_length - 25], center = true);

        // サーボスペース
        translate([0, 0, shin_length/2 + 5])
            cube([ds3218_width + 1, ds3218_depth + 1, ds3218_height + 1], center = true);
    }
}

// =============================================================================
// モジュール: 足
// =============================================================================
module foot() {
    difference() {
        union() {
            // 足本体
            hull() {
                // つま先側
                translate([foot_length/3, 0, foot_height/2])
                    resize([foot_length/2, foot_width, foot_height])
                        sphere(d = 20, $fn = 32);

                // かかと側
                translate([-foot_length/3, 0, foot_height/2])
                    resize([foot_length/3, foot_width * 0.8, foot_height])
                        sphere(d = 20, $fn = 32);
            }

            // 足首接続部
            translate([0, 0, foot_height])
                cylinder(h = 15, d = ankle_joint_diameter + 10, $fn = 32);
        }

        // 足首軸穴
        translate([0, 0, foot_height + 7.5])
            rotate([0, 90, 0])
                cylinder(h = ankle_joint_diameter + 20, d = 6, center = true, $fn = 32);

        // サーボスペース
        translate([0, 0, foot_height + 10])
            cube([ds3218_width + 1, ds3218_depth + 1, 20], center = true);

        // 足裏くぼみ（TPU挿入用）
        translate([0, 0, 2])
            resize([foot_length - 5, foot_width - 5, 5])
                sphere(d = 20, $fn = 32);
    }
}

// =============================================================================
// モジュール: 足裏（TPU製）
// =============================================================================
module foot_sole() {
    // TPUで印刷する滑り止めパーツ

    difference() {
        resize([foot_length - 6, foot_width - 6, 4])
            sphere(d = 20, $fn = 32);

        // 上半分カット
        translate([0, 0, 5])
            cube([foot_length, foot_width, 10], center = true);
    }

    // 滑り止めパターン
    for (x = [-foot_length/3 : 10 : foot_length/3]) {
        for (y = [-foot_width/3 : 10 : foot_width/3]) {
            translate([x, y, -1])
                cylinder(h = 2, d = 5, $fn = 6);  // 六角形パターン
        }
    }
}

// =============================================================================
// モジュール: 完全な脚
// =============================================================================
module complete_leg(is_right = true) {
    // 股関節ブロック
    color("gray")
        translate([0, 0, thigh_length + shin_length + foot_height + 30])
            hip_block();

    // 大腿部
    color("white")
        translate([0, 0, shin_length + foot_height + 15])
            thigh();

    // 下腿部
    color("white")
        translate([0, 0, foot_height + 15])
            shin();

    // 足
    color("white")
        foot();

    // 足裏（TPU）
    color("darkgray")
        foot_sole();
}

// =============================================================================
// モジュール: DS3218サーボ（参考モデル）
// =============================================================================
module ds3218_servo() {
    color("black") {
        cube([ds3218_width, ds3218_depth, ds3218_height], center = true);
        translate([0, ds3218_depth/2 - 7, ds3218_height/2])
            cylinder(h = 5, d = 6, $fn = 32);
    }
}

// =============================================================================
// 出力
// =============================================================================

// 完全な脚
complete_leg(true);

// 個別パーツ出力用
// hip_block();
// thigh();
// shin();
// foot();
// foot_sole();

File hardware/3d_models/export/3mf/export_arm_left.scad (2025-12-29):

// 左腕 - 水色縞模様
use <../parts_for_3mf.scad>
arm_left();

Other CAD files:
hardware/3d_models/korosuke_print/sg90-servomotor-arms-1.snapshot.33/SG90_preview_model/SG90_preview_model.step
hardware/3d_models/korosuke_print/stl/light_blue/arm_ring_x16.stl
hardware/3d_models/korosuke_print/stl/light_yellow/hand_x2.stl
hardware/3d_models/korosuke_print/stl/navy/leg_x2.stl
hardware/3d_models/export/3mf/export_arm_right.scad
hardware/3d_models/accessories/sword.scad
hardware/3d_models/body/torso_frame.scad
hardware/3d_models/body/torso_shell.scad
hardware/3d_models/export/3mf/arm_left.3mf
hardware/3d_models/export/3mf/arm_right.3mf
hardware/3d_models/export/3mf/body_torso.3mf
hardware/3d_models/export/3mf/export_body_torso.scad
hardware/3d_models/export/3mf/export_corosuke_full.scad
hardware/3d_models/export/3mf/export_foot_left.scad
hardware/3d_models/export/3mf/export_foot_right.scad
hardware/3d_models/export/3mf/export_hand_left.scad
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

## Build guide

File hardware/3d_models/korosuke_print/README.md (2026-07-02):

# korosuke_print — 印刷用マスター(色分割・電子部品統合)

観賞用`exterior/`を、**実際に刷って組んで電子部品が収まる**外装に再設計したもの。
Webリサーチ(2026-06-25, Wikipedia/pixiv百科/Fandom/公式グッズ)反映済み。

## 設計の柱
1. **色ごとにパーツ分割** — 単色プリンタでもフィラメント交換だけで原作配色
2. **GC9A01目ディスプレイ統合** — 顔に窓φ33+モジュールポケットφ37.6、白ベゼルφ50
   (「目はライトにもなる」公式設定あり=発光目はキャラ準拠!)
3. **RDK X5ケースベイ** — 胴内に縦置きレール(91.4×62.4×27.1+遊び)、背面ハッチでポートアクセス
4. **ESP32-S3トレイ** — 後頭部内壁、首穴φ46でケーブルを胴へ
5. 全パーツ壁3mm中空・ピン/リップ位置決め・平置き印刷向き

## 色プレート(SHOW番号 = 1パーツ1STL)
| 色 | SHOW | パーツ |
|---|---|---|
| 🟠 橙(頭/胴) | 11,12 | head_front / head_back(前後割り+ピン4) |
| 🟠 | 13,14,15,16 | hand×2 / collar / **jacket_shell** / back_panel |
| ⚪ 白 | 21 | eye_bezel×2(化粧リング) |
| 🔴 赤 | 31,32,33,34,35,54 | nose(カメラ穴φ7.5) / button×4 / mage軸 / 鞘 / **頬×2** / arm_ring_B×4-5 |
| ⚫ 黒 | 41,42,43 | topknot_fan / wheel / hilt |
| 🔵 紺青 | 51,52,53 | arm_ring_A×5 / leg×2 / foot×2 |

腕=A/Bリング交互スタック(中心φ12穴にロープ/配線)→ 単色機で縞を実現。

## パレット
- `PALETTE="vcd"`(既定): メディコムVCD準拠(橙頭・腰刀)
- `PALETTE="anime"`: 1988フジTV本放送版 — **頭=淡黄/胴=橙の2トーン**、赤頬
- アニメ版の刀は本来**背負い**(未実装、腰差しで代用)。鞘の白菱形は塗装/シール推奨

## 未確定領域(リサーチ結論)
口の正確な形・足元の形状・眉耳(=無しと推定)は公式文書なし → 創作補完済み。
準拠元は提出物で明記すること。

Character (C) Fujiko F. Fujio — fan-made, non-commercial tribute. Design: CC BY 4.0.

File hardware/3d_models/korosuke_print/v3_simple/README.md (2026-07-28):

# 胴体 v3 (simple) — 作り直したシンプル版

複雑化した v2 を整理し、**部品3種＋FreeCADで開けるCSG**にした版。
ソース: [torso_v3.scad](torso_v3.scad)

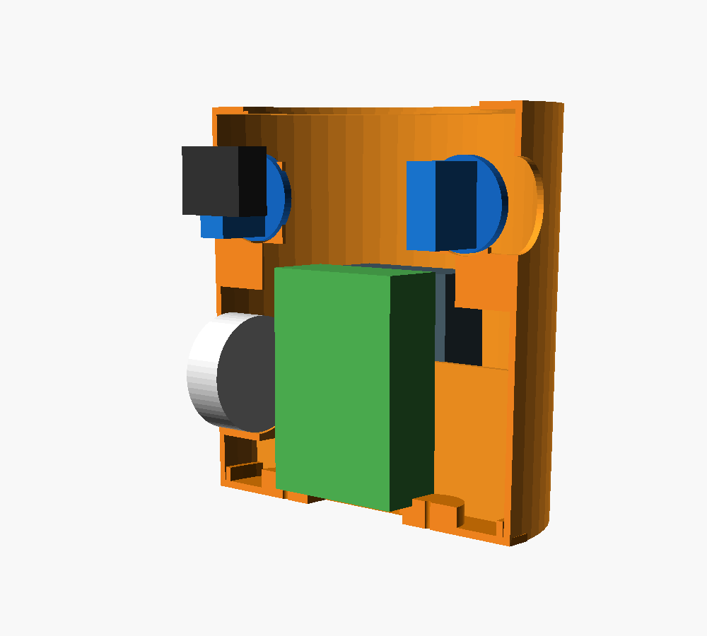
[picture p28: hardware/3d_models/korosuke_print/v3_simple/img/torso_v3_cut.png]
cut


## 方針
- **mirror() / offset() / 円錐との交差 を一切使わない** → FreeCADで `.csg` がそのまま開ける（`Null input shape` が出ない）。
- RDK/バッテリーは**ベルクロ固定**（レール等の複雑物を廃止）。ESP32-S3+ブレッドボードは頭部へ。
- 全パーツ平置き・サポート不要。

## パーツ（3種）
| SHOW | ファイル | 色 | 個数 | 備考 |
|---|---|---|---|---|
| 1 | `stl/shell_v3.stl` | 🟠橙 | 1 | 胴シェル＋**サーボ台一体**（十字ホーンのSG90×2） |
| 2 | `stl/bottom_v3.stl` | 🟠橙 | 1 | 底板（ケーブル窓・脚ボス・支柱ノッチ） |
| 3 | `stl/lid_v3.stl` | 🟠橙 | 1 | 天面リッド（首穴φ46・落とし込み） |

## 搭載
| 部品 | 寸法 | 位置 |
|---|---|---|
| RDK X5ケース | 91.4×62.4×27.1（上下+5mm余裕） | 中央・縦置き（ベルクロ） |
| モバイルバッテリー | 62×24×95（`PB_*`可変） | 背面（ベルクロ） |
| SG90 ×2（十字ホーン） | 軸(x=±58, z=127) | 腕穴直下のクレードル。掃引円は壁/床とクリア |
| スピーカー | φ50×18.5（秋月WYGD50D-8） | 前面グリル裏 |
| 胸カメラ | φ12窓（Arducam IMX291推奨） | 前面 z=100 |

## SG90の向き（重要）
- 十字ホーンは軸まわり**半径≈16mmで掃引** → ホーン面をクレードル**背面の後ろ(y≈3)**に置き干渉回避。
- **軸端を外＝腕穴側**に向けて上から落とし込み、内側タブを**M2×1**で固定（左右で逆）。
- ホーンは「真上→内側」だけ使用（外側は壁に当たる）。

## FreeCADで見る（確実な方法）
FreeCAD 1.0 の **CSGインポータはOCCTブーリアン失敗（`Null input shape`）で不安定**なので、
**ネイティブ文書 `.FCStd` を用意しました**（Part APIで生成し、freecadcmdで検証済み）:

- **`torso_v3.FCStd`** を **ファイル > 開く**（またはダブルクリック）
  → 12個のソリッド（シェル＋RDK＋バッテリー＋SG90×2＋十字ホーン＋スピーカー＋サーボ台）が
     **編集可能ソリッド**で開きます。CSGインポータを通さないのでエラーになりません。
- 色付き・自動フィットで見たいときは **マクロ > マクロ… > `torso_v3_freecad.py` > 実行**。
- （STL版 `stl/*.stl` も同フォルダにあり、こちらも確実に開けます。）

> `.csg` はFreeCADのバグで開けないため非推奨。`.FCStd` かマクロを使ってください。

## 印刷前の現物合わせ
- バッテリー実寸 → `PB_W/PB_T` / カメラ基板ピッチ → （窓φ12は共通）。
- 変更したら該当SHOWだけ再レンダリング:
  ```
  openscad -o stl/shell_v3.stl -D SHOW=1 torso_v3.scad
  ```

*v2（rails/deck/カメラボス付きの詳細版）は上位フォルダに残置。v3は「まず動く最小構成」。*

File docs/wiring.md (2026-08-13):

# Korosuke — Wiring & connection diagram

How the main parts connect: RDK X5 / ESP32-S3 / camera / MAX98357A / speaker / eyes /
arm servos, and **two power rails** (power bank for the RDK X5 + LiPo for the servos) with a
**shared common ground**.

```mermaid
flowchart LR
  %% All parts are boxes. Colour = category. Pin numbers are on the wires (edge labels).
  PB["🔋 Mobile battery<br/>(power bank) 5V/3A"]:::power
  LIPO["🔋 LiPo<br/>(for servos)"]:::power
  RDK["🧠 RDK X5 (10 TOPS)<br/>(brain — everything on-device)"]:::main
  ESP["ESP32-S3<br/>(eyes/arms MCU)"]:::compute
  AMP["MAX98357A<br/>I2S amp (GAIN=9dB)"]:::module
  EYES["2× GC9A01<br/>round LCD (eyes)"]:::module
  CAM["📷 Camera C270<br/>(built-in mic)"]:::periph
  BTN["⏻ Shutdown button"]:::periph
  SPK["🔊 φ50 speaker"]:::periph
  SRV["💪 2× SG90<br/>servos (arms)"]:::periph

  PB   -->|"USB-C 5V/3A"| RDK
  CAM  -->|"USB (video + audio)"| RDK
  BTN  -->|"pin18(GPIO24) / pin20(GND)"| RDK
  RDK  -->|"USB (power + data · ttyACM0)"| ESP
  RDK  -->|"5V:pin2/4 · GND:pin6<br/>BCLK:pin12 · LRC:pin35 · DIN:pin40"| AMP
  AMP  -->|"analog +/−"| SPK
  ESP  -->|"SPI: SCK12·MOSI11·DC9·RST8<br/>CS_L10·CS_R14 · 3V3·GND"| EYES
  ESP  -->|"PWM: GPIO4(L) / GPIO5(R)"| SRV
  LIPO -->|"LiPo voltage direct (no BEC)"| SRV
  LIPO -.->|"common GND ⚠ (required)"| ESP

  classDef power   fill:#f6b73f,color:#3a2a00,stroke:#c98a12,stroke-width:2px;
  classDef compute fill:#1f6feb,color:#fff,stroke:#58a6ff,stroke-width:2px;
  classDef module  fill:#8957e5,color:#fff,stroke:#bc8cff,stroke-width:2px;
  classDef periph  fill:#2da44e,color:#fff,stroke:#3fb950,stroke-width:2px;
  classDef main    fill:#1f6feb,color:#fff,stroke:#ffffff,stroke-width:4px,font-size:22px;
```

**Legend**: 🟡 Power · 🔵 Compute (board) · 🟣 Module · 🟢 Peripheral.
All parts are boxes; **pin numbers are on the wires (edge labels)**.

## Connection table

| From | Pin / port | → To | Pin | Signal |
|---|---|---|---|---|
| Mobile battery | USB-C 5V/3A | RDK X5 | USB-C (power) | RDK power |
| RDK X5 | USB-A | ESP32-S3 | USB (native CDC) | **power + data** (`/dev/ttyACM0`) |
| RDK X5 40-pin | **2/4**=5V, **6**=GND | MAX98357A | VIN, GND | amp power |
| RDK X5 40-pin | **12**=BCLK, **35**=LRC, **40**=DIN | MAX98357A | BCLK/LRC/DIN | I2S audio out |
| MAX98357A | +/− | φ50 speaker | — | analog out |
| RDK X5 40-pin | **18**(GPIO24), **20**(GND) | Push button | — | safe shutdown |
| RDK X5 | USB-A | Camera C270 | USB | video + mic |
| ESP32-S3 | 12/11/9/8/10/14 + 3V3/GND | 2× GC9A01 | SCK/MOSI/DC/RST/CS_L/CS_R | eyes (shared SPI, separate CS) |
| ESP32-S3 | **GPIO4**(L) / **GPIO5**(R) | 2× SG90 | signal | arm servo PWM |
| LiPo | voltage direct | SG90 servos | V+ | **servo power (no BEC/regulator)** |
| LiPo | GND | ESP32-S3 / RDK | GND | **common ground (required)** |

## Notes
- **Two power rails**: the RDK X5 runs from the power bank (5V/3A+, a good USB-C cable — a
  half-seated / thin cable causes brown-outs → [power_usb_troubleshooting.md](power_usb_troubleshooting.md)).
  The servos run from a **separate LiPo** (so servo inrush current can't drop the RDK).
- **Common ground is required**: tie the LiPo (servo) GND to the ESP32-S3 / RDK GND, or the
  servo PWM will be unstable.
- **Servos run directly on the LiPo voltage** — no 5V BEC/regulator is fitted. Choose a LiPo
  within the SG90 range (4.8–6V); avoid over-voltage.
- **ESP32-S3 is wired with a single USB cable** (power + `ttyACM0` data). To use a direct UART
  instead: ESP32 RX=GPIO18 / TX=GPIO17 ([firmware/corosuke_eyes](../firmware/corosuke_eyes)).
- **MAX98357A GAIN**: floating = 9 dB (default). Details → [rdk_x5_40pin_i2s_max98357a.md](rdk_x5_40pin_i2s_max98357a.md).
- Full eye pinout: see the header comment in [firmware/corosuke_eyes/src/main.cpp](../firmware/corosuke_eyes/src/main.cpp).

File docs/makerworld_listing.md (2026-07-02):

# MakerWorld アップロード記入シート — RDK X5 Modular Case

MakerWorld(https://makerworld.com)の「Upload」フォームに、下記をそのままコピペすればOK。

---

## アップロードするファイル

**3Dモデル(4ファイル、MakerWorldは3MF推奨):**
```
C:\Users\robostadion\OneDrive\claudecode\robot\rdk-x5-modular-case\stl\case_base.3mf
C:\Users\robostadion\OneDrive\claudecode\robot\rdk-x5-modular-case\stl\lid_default.3mf
C:\Users\robostadion\OneDrive\claudecode\robot\rdk-x5-modular-case\stl\lid_open.3mf
C:\Users\robostadion\OneDrive\claudecode\robot\rdk-x5-modular-case\stl\lid_vesa.3mf
```
(STL版も同フォルダにあり。3MFで問題なければそちらを推奨)

**カバー画像(1枚目=サムネイル):**
```
C:\Users\robostadion\OneDrive\claudecode\robot\rdk-x5-modular-case\images\assembly_preview.png
```
**追加画像(5枚):**
```
images\board_fit_verification.png  ← ★実物基板との整合検証(これが信頼の証)
images\case_base.png / lid_default.png / lid_open.png / lid_vesa.png
```

---

## フォーム記入欄

### Design Name(タイトル)
```
RDK X5 Modular Case — Closed / Open / VESA mount (Parametric, CC BY 4.0)
```

### Category(カテゴリ)
`Gadgets` → `Computer` （無ければ `Electronics` / `Tools`）

### Tags(タグ、最大10程度)
```
RDK X5, D-Robotics, ROS2, robotics, SBC, case, enclosure, edge-AI, OpenSCAD, single-board-computer
```

### License(ライセンス)
**Creative Commons - Attribution (CC BY 4.0)**

### Model Origin / Source(モデルの出自)
**Original design**（オリジナル設計）
※基板外形は D-Robotics 公式DXFから採寸したが、ケース設計自体はオリジナル。

### Description(説明文 — マークダウン可、そのままコピペ)
```
The first open-source 3D-printable case for the D-Robotics RDK X5 8GB Dev Kit
(Sunrise X5 SoC, 10 TOPS BPU).

WHY THIS EXISTS
As of mid-2026, RDK X5 had no community 3D-printable case anywhere — not on
MakerWorld, Printables, or Thingiverse. This fills that gap with a modular,
fully parametric OpenSCAD design.

ONE BASE, FOUR LIDS
🔵 Default — closed lid with cooling slits (everyday use)
🟢 Open — honeycomb vent field (heatsink fully exposed, max airflow)
🟡 VESA Mount — 50×50 M4 4-hole bracket pattern (board is too small for full VESA-75)
🟣 Fan — 40 mm fan mount (32 mm M3 pattern) with honeycomb intake grille + finger guard

FAN LID — RECOMMENDED HARDWARE (tested)
• Fan: 40 × 40 × 10 mm (4010), 5 V, 2-wire — the exact one I used
• Screws: 4 × M3 × 15 mm — a perfect fit through the fan into the lid bosses
• Power: 40-pin header, pin 4 = 5V, pin 6 = GND (runs full-speed when powered)
• Measured cooling (assembled, lid on): idle 66 C passive -> 41 C with fan (−25 C)

All lids snap onto a common base (press-fit lip + a full-perimeter snap ridge/groove).
The PCB is held by an outer clamp, so the stock heatsink mounting holes
stay fully accessible.

SPECS — every port cutout is data-accurate
• PCB outline from official D-Robotics V1P0 DXF (85 × 56 mm, C3 chamfered corners)
• Every connector position (USB-A ×2, RJ45, HDMI, audio, USB-C ×2, UART debug,
  40-pin GPIO, microSD, fan) extracted from the official STEP/DXF and VERIFIED by
  overlaying the real board mesh — see the board-fit verification image.
• Case footprint: ~89 × 60 × 30 mm
• Chamfered top edges, support-free, PLA / PETG, 2.2 mm walls

PRINT SETTINGS
• Layer height: 0.20 mm
• Walls / perimeters: 3
• Infill: 20% gyroid
• Supports: none

FILES
• case_base — print once
• lid_default / lid_open / lid_vesa / lid_fan — pick the lid(s) you want
All lids fit the same base.

SOURCE & REMIX
Full parametric OpenSCAD source on GitHub:
https://github.com/gurimaruking/rdk-x5-modular-case

LICENSE
CC BY 4.0 — share / remix / commercial use OK with credit.

DISCLAIMER
Unofficial community design, not affiliated with D-Robotics. PCB geometry
derived from D-Robotics' publicly released mechanical drawings.

Made as a community contribution from Project Korosuke (コロ助) — my entry
in the D-Robotics Robotics Dream Keeper Challenge.

#RDKX5 #DRobotics #ROS2 #edgeAI #robotics
```

### Designer Notes / 補足(任意)
```
Designed in OpenSCAD — every dimension is a parameter, so you can tweak
fit gap, wall thickness, top clearance, and VESA pattern in the source.
Camera-cutout and DIN-rail lids are on the roadmap; PRs welcome on GitHub.
```

---

## 印刷プロファイル(任意だが強く推奨)

MakerWorldは **Bambu Studioでスライスした印刷プロファイル付き**だと「Print Profile」バッジが付き、表示順位・ポイントで有利(Top Creator狙いに効く)。
余裕があれば:
1. Bambu Studioで各3MFを開く
2. PLA/PETG, 0.2mm, 3 walls, 20% infill, サポート無し でスライス
3. プロファイルを保存してMakerWorldにアップロード時に添付

なくてもモデル単体でアップロード可能。

---

## アップロード後にやること
- [ ] 公開URLを控える
- [ ] GitHub README / Discord告知文にMakerWorldリンクを追記
- [ ] Printables / Thingiverse にも同内容で展開(Task #13)

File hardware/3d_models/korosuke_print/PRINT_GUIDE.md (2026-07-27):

# コロ助 印刷ガイド(色別プレート)

> **🆕 胴体v2あり**(2026-07-27): SG90ネジ止め・中段デッキ(ESP32+ブレッドボード)・天面開口リッド・
> 胸カメラポケット・フットベース(排線溝付き)。**印刷データ一式 → [v2/](v2/)**
> ([印刷ガイド](v2/PRINT_GUIDE_V2.md) / [torso_v2.scad](torso_v2.scad) /
> 設計解説 [docs/torso_v2_design.md](../../../docs/torso_v2_design.md))。
> 以下の胴パーツ(jacket_shell/bottom_plate)はv1。頭/腕/脚はv1・v2共通。

STLは `stl/<色>/` に配置。ファイル名の `_xN` = **スライサでN個に複製**して印刷。
共通設定: PLA / 0.2mm / 壁3 / インフィル15% / サポートは下記指定のみ。

> **採用配色(2026-07-03決定): アニメ2トーン = 頭・手=淡黄 / 胴=橙**

## 🟡 淡黄(頭まわり)
| ファイル | 個数 | サポート | 備考 |
|---|---|---|---|
| head_front_x1.stl | 1 | **ツリー** | 顔上向き平置き。目窓/鼻穴/口が顔面に出る |
| head_back_x1.stl | 1 | **ツリー** | 内側にESP32トレイ棚 |
| hand_x2.stl | **2** | **ツリー** | 中空球。手首穴を横に(手はゴムまり=頭と同色) |

## 🟠 橙(胴まわり)
| ファイル | 個数 | サポート | 備考 |
|---|---|---|---|
| jacket_shell_x1.stl | 1 | 不要 | 高さ165mm。ベイレール/ハッチ/グリル入り |
| back_panel_x1.stl | 1 | 不要 | 背面ハッチ蓋 |
| collar_x1.stl | 1 | 不要 | 首リング |
| bottom_plate_x1.stl | 1 | 不要 | **底板(骨盤)** — 裾に圧入。脚ボス×2に脚を差す。ケーブル穴付き |

## ⚪ white
| eye_bezel_x2.stl | **2** | 不要 | 化粧面が下=一層目がキレイな面になる |

## 🔴 red
| ファイル | 個数 | サポート |
|---|---|---|
| nose_x1.stl | 1 | **ツリー**(球) |
| cheek_x2.stl | **2** | 不要(ドーム平置き) |
| button_x2.stl | **2** | 不要 |
| topknot_stalk_x1.stl | 1 | 不要 |

## ⚫ black
| topknot_fan_x1.stl(※スライサで「自動修復」が出るが正常・そのまま可) | 1 | **ツリー**(扇刃) |

## 🩵 light_blue(水色 — 腕・脚・足)
| ファイル | 個数 | サポート | 備考 |
|---|---|---|---|
| arm_base_x2.stl | **2** | 不要 | 蛇腹の付け根(肩側φ44→φ28へフレア)。左右に1個ずつ、腕の一番下 |
| arm_ring_x16.stl | **16**(左右8+8・同形) | 不要 | 蛇腹リング。base の上に8個スタック |
| leg_x2.stl | **2** | 不要 | |
| foot_x2.stl | **2** | 不要(底面フラット) | |

## 組立メモ
1. **目**: GC9A01を頭前パーツ内側からポケットへ → 白ベゼルを外から窓に差す → ESP32-S3は後頭部トレイ、配線は首穴から胴へ
2. **頭**: 前後をピン4本で合わせ(接着 or テープ仮組)
3. **腕**: arm_base(付け根)の上に arm_ring を8個スタック(継手はめ込み)、中心穴にロープ/配線 → 上端を手首へ
4. **胴**: RDK X5ケースを裾から縦に挿入(ベイレール保持)→ 背面ハッチから配線
5. **頬/鼻/ボタン**: 接着(鼻はカメラ穴φ7.5にUSBカメラのレンズを合わせられる)
6. 鞘の白菱形は塗装/カッティングシートで

推定フィラメント: 全身で約400-500g(胴体が最大)。

## 📷 胸カメラ(任意・ELP双眼カメラを胸に仕込む場合)
> 詳細ソースは `stereo_cam/chest_cam.scad`。胴に外から当ててM2×4でネジ止め。
| ファイル | 色 | 個数 | サポート | 備考 |
|---|---|---|---|---|
| orange/chest_plate_x1.stl | 🟠橙 | 1 | 箱側を下=最小 | パネル+基板箱一体 |
| red/chest_bezel_x2.stl | 🔴赤 | **2** | 不要 | 胸ボタン=レンズ化粧リング |
| gray/chest_lid_x1.stl | ⚪灰 | 1 | 不要 | 基板押さえ蓋(胴内側・隠れる) |
| gray/chest_pushnut_x4.stl | ⚪灰 | **4** | 不要 | ピン圧入ナット |

必要ハード: M2ネジ×4(胴固定)+ カメラ固定ピンはプレート一体。基板はベンチで固定→胴へ外からネジ4本。

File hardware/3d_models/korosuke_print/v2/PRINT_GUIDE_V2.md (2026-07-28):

# 胴体v2 印刷ガイド

ソース: [../torso_v2.scad](../torso_v2.scad) ／ 設計解説: [docs/torso_v2_design.md](../../../../docs/torso_v2_design.md)
共通設定: **PLA / 0.2mm / 壁3 / インフィル15%**。全パーツ**平置き・サポート不要**（例外は備考）。
頭・襟・背面パネル・腕・脚・ボタンは v1 のまま使用（外形互換）。

## 🟠 橙 (orange/)

| ファイル | 個数 | 備考 |
|---|---|---|
| jacket_shell_v2_x1.stl | 1 | そのまま上向き。デッキ柱4本は床から立つ=サポート不要。天面リングは短いブリッジ(v1天板より楽)。**胸カメラボス/スピーカー座は水平突起 — 多少垂れても機能OK**(綺麗にしたければその2箇所だけツリー) |
| bottom_plate_v2_x1.stl | 1 | 底板。柱ノッチ4・RDK USB窓56×24・バッテリー窓・ベルクロスロット・M3×4 |
| top_lid_x1.stl | 1 | 天面リッド(φ125)。裏の指掛かり座ぐりが下面に来る向きでそのまま |

## ⚪ 灰 (gray/) — 内部部品(色自由)

| ファイル | 個数 | 備考 |
|---|---|---|
| mid_deck_x1.stl | 1 | 中段デッキ。ブレッドボード枠が上 |
| servo_bracket_x2.stl | (0) **不要になりました** | SG90はシェル一体の**コの字タワー**(ホーン=腕穴位置)に上から落とし込み→内側タブM2×1(軸側を外=腕穴側へ)。この別体ブラケットは旧デッキ吊り方式のオプション |
| foot_base_v2_x1.stl | 1 | 上面のまま印刷。裏面排線溝の天井(26mm)は自動ブリッジでOK |

## 🔴 赤 (red/)

| ファイル | 個数 | 備考 |
|---|---|---|
| cam_bezel_x1.stl | 1 | 化粧面が下=一層目が化粧面 |

推定フィラメント: 合計 ~420-480g（shell ~200g / base ~80g / plate ~60g / deck ~45g / lid ~25g / 他小物）

## 必要ハードウェア

| 品 | 数 | 用途 |
|---|---|---|
| SG90 + 付属タッピングM2 + シングルホーン | 2 | 腕ロープ牽引(ブラケット窓へ、**軸側の端を内側に向ける**) |
| M3×8 タッピング | 4+4+4 | デッキ→柱 ／ ブラケット→デッキ ／ (任意)底板→フットベース |
| M2×6 タッピング | 4 | カメラ基板→胸ボス |
| ベルクロバンド | 1-2 | モバイルバッテリー固定 |
| アクリル両面テープ | — | フットベース(現行方式のまま可) |

## 印刷前チェック(現物合わせ)

1. **モバイルバッテリー実寸** → `PB_W`(幅・既定62) / `PB_T`(厚・既定24) を実測値+1mmに
2. **カメラ基板の穴ピッチ** → `CAM_PITCH`(既定28=Arducam IMX291) を実測に
3. 変更したら該当SHOWのみ再レンダリング:
   ```
   openscad -o v2/orange/jacket_shell_v2_x1.stl -D "SHOW=1" torso_v2.scad
   ```

## 組立(要約 — 詳細は設計doc)

裾: フットベース(テープorM3)→底板 → RDK X5をレールへ・バッテリーをトレイへ →
SG90をブラケットへ(M2×2)→デッキ裏へ(M3×2) → デッキを柱4本へ(M3×4) →
ブレッドボード(ESP32-S3ごと)を枠へ → ロープ: 腕穴→デッキφ8穴→ホーン先端
(**ホーン12時=腕下げ・内側回し=引き**。左右逆・ESP32で反転) →
カメラ基板(M2×4)+赤ベゼル → スピーカーを座へ結束 → リッド→襟→頭

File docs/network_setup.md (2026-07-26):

# コロ助 ネットワーク構成（メンテ用）

RDK X5 への接続方法と、eth0 固定IPの設定・トラブル対処をまとめる（保守用）。

## 到達方法（どちらでもSSH可）
| I/F | アドレス | 用途 | 備考 |
|---|---|---|---|
| **eth0** | **192.168.0.200/24（固定）** ＋ DHCP動的 | **LAN経由の保守アクセス** | 電源ONで自動付与（再起動で実証済み） |
| usb0 | 192.168.128.10/24（固定） | **Type-C(USB-C)直結の生命線** | PCとType-Cケーブルで直結(USBガジェット)。LANが不通でも必ず入れる |

- LAN側: `ssh sunrise@192.168.0.200`（パスワード sunrise）
- USB直結: `ssh sunrise@192.168.128.10`
- Web モニタ: `http://192.168.0.200:8080/` または `http://192.168.128.10:8080/`

## 元のネットワーク
- LAN ネットワークアドレス: **192.168.0.0/24** / ゲートウェイ **192.168.0.1**
- 元々 eth0 は DHCP のみ（例: 192.168.0.127 が動的付与されていた）。
- 保守で毎回IPが変わると不便なので、**DHCPを残したまま固定IP 192.168.0.200 を併設**した。

## netplan 設定（/etc/netplan/01-hobot-net.yaml, renderer=NetworkManager）
```yaml
network:
  version: 2
  renderer: NetworkManager
  ethernets:
    eth0:
      dhcp4: true
      addresses: [192.168.0.200/24]   # ← 追加した固定IP(DHCPと併用)
    usb0:
      dhcp4: no
      addresses: [192.168.128.10/24]
      gateway4: 192.168.128.1
    usb1:
      dhcp4: no
      addresses: [192.168.128.10/24]
```
適用: `sudo netplan apply`（backup: `01-hobot-net.yaml.bak`）。

## ハマりどころ（重要）
`netplan apply` 後も固定IPが付かないことがある。原因は **NetworkManager に古い接続プロファイルが残存**し、
netplan生成の新プロファイル（固定IPを持つ）を **シャドウ** するため。

- 症状: `ip addr show eth0` に 192.168.0.200 が出ない。
- 確認: `nmcli -t -f NAME,UUID,FILENAME connection show | grep eth0`
  - `/etc/NetworkManager/system-connections/netplan-eth0.nmconnection` … 古い残骸（固定IP無し・アクティブ）
  - `/run/NetworkManager/system-connections/netplan-eth0.nmconnection` … netplan生成（`address1=192.168.0.200/24` あり）
- 対処:
  1. 固定IPを持つ方を有効化: `sudo nmcli connection up <その UUID>`
  2. 古い残骸を削除: `sudo nmcli connection delete <古い UUID>`（/etc の残骸が消える）
  3. 残る接続が `ACTIVE=yes / AUTOCONNECT=yes` なら再起動でも自動付与される。
- 検証コマンド: `ip -4 addr show eth0 | grep inet`（.200 と DHCP動的の両方が出ればOK）

## 変更時の安全策
- 作業は **usb0(192.168.128.10) 経由**で行えば、eth0 をいじってもロックアウトしない。
- 固定IPを変える場合は、まず `ping -c1 <候補>` で空きを確認（DHCPプールと衝突しない高位アドレス推奨）。

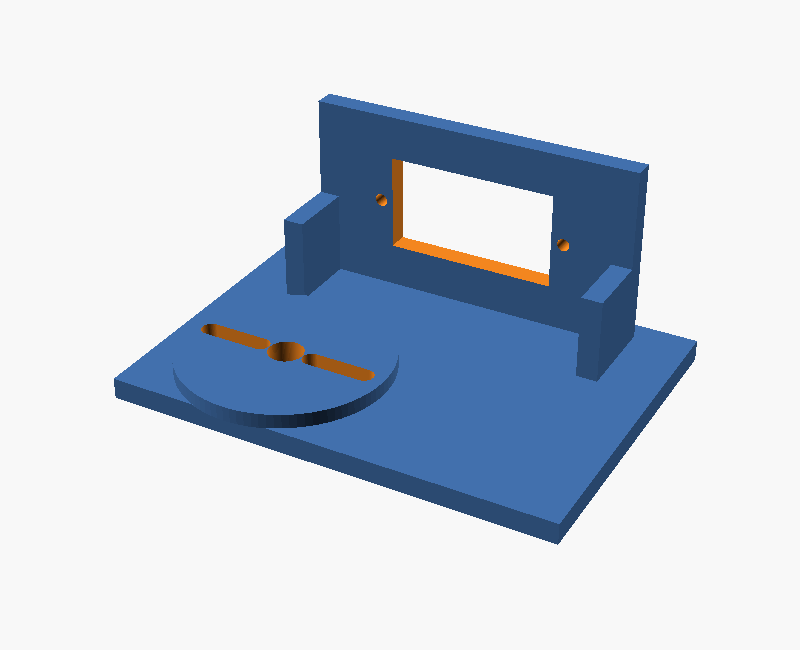
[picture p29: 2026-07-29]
hardware/3d_models/korosuke_print/v3_simple/img/base_diff_v2_coupon.png

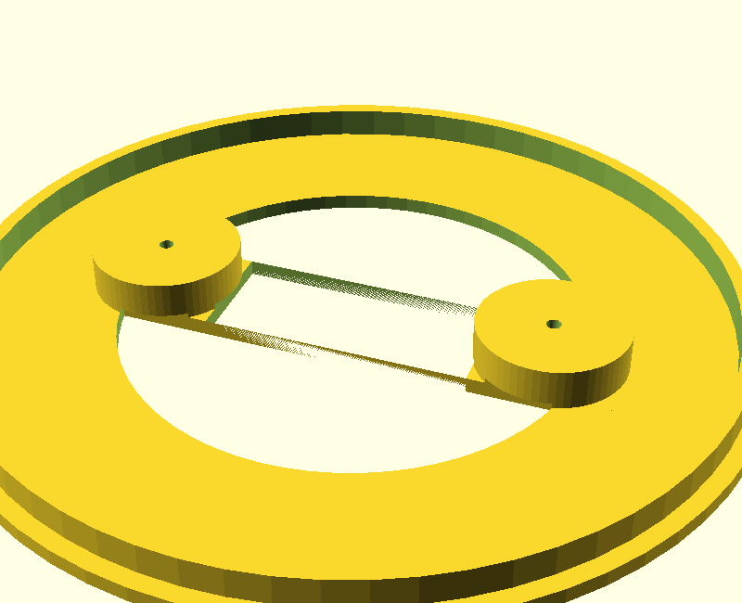
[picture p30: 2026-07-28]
hardware/3d_models/korosuke_print/v3_simple/img/torso_v3_bottom.png

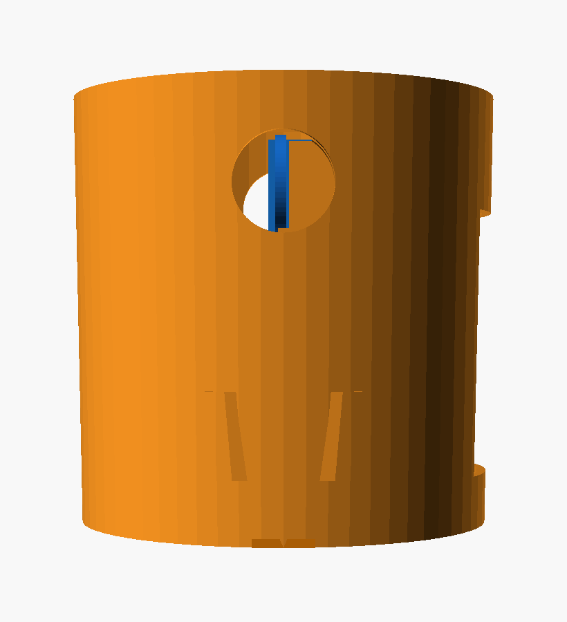
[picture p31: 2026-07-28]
hardware/3d_models/korosuke_print/v3_simple/img/torso_v3_left.png

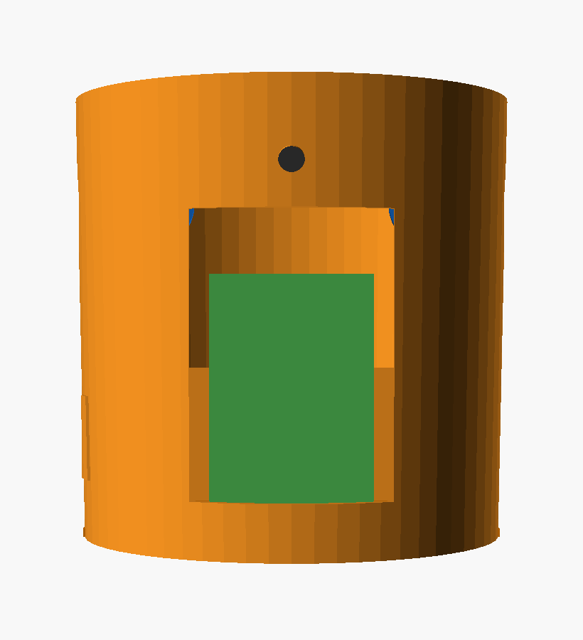
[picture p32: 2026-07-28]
hardware/3d_models/korosuke_print/v3_simple/img/torso_v3_shell.png

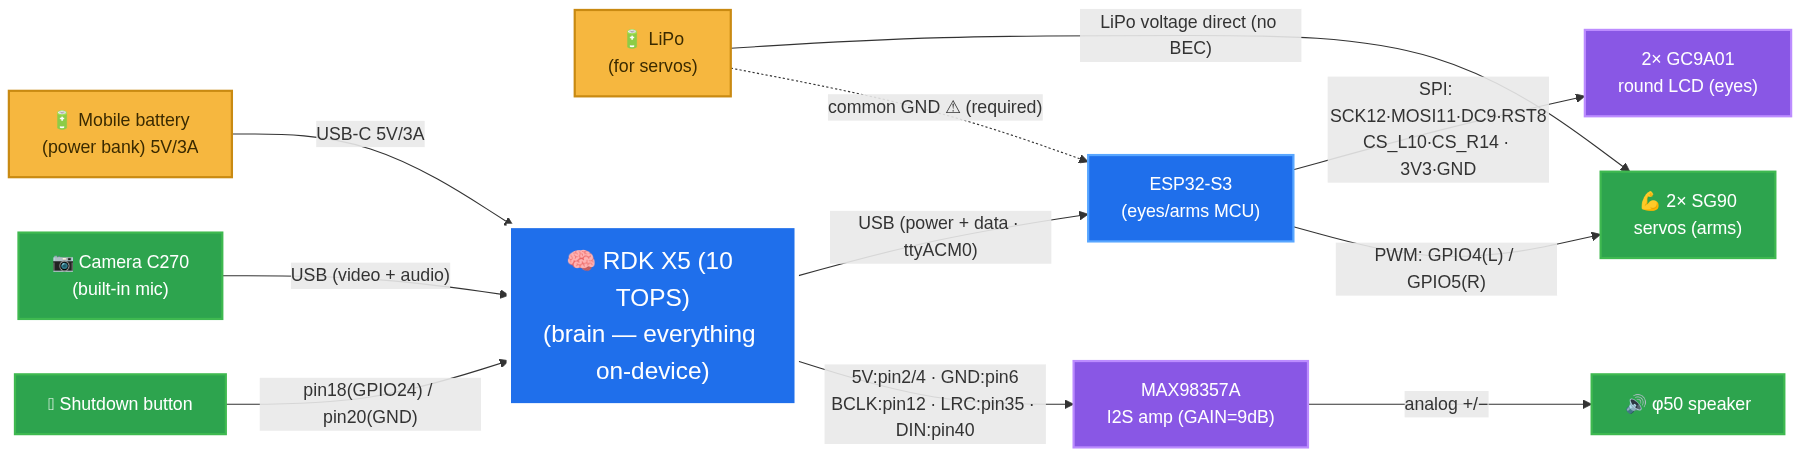
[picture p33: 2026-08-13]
docs/slides/img/hw_wiring.png

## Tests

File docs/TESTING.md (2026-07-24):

# コロ助 テストコマンド集(チートシート)

> 対象: RDK X5 (SSH), ESP32-S3(目), Windows(PlatformIO)。2026-07-24時点で全て動作確認済み。
> **鉄則**: オーディオデバイスは番号でなく名前で指定(`plughw:Microphone,0`=カメラマイク / `plughw:duplexaudio,0`=スピーカー)。カード番号は再起動で入れ替わる。

## 0. 接続

```bash
ssh sunrise@192.168.128.10          # パスワード: sunrise (ホスト名 korosuke)
```

Windowsから中身を触るヘルパー(paramiko、SSH不要でワンショット実行):
```bash
# scratchpad/rdk.py  —  run <cmd> / put <local> <remote> / get <remote> <local>
python rdk.py run "uptime"
```

## 1. 👁 目(ESP32-S3) — PCからでもRDKからでも

### コマンド言語(115200bps テキスト行)
```
ping        → pong    emo <neutral|happy|sad|angry|surprised|sleepy>
blink       wink <l|r>   gaze <x> <y>  (-1.0〜1.0)   idle <on|off>
```

### RDK X5から目を直接叩く(/dev/ttyACM0)
```bash
python3 - <<'EOF'
import serial, time
p = serial.Serial('/dev/ttyACM0', 115200, timeout=0.5); time.sleep(0.5)
for cmd in ['ping','emo happy','gaze 0.5 0','blink']:
    p.write((cmd+'\n').encode()); time.sleep(0.4); print(cmd, '->', p.read(60))
p.close()
EOF
```

### ROS 2で目デモ(8表情巡回) ← M2実証
```bash
source /opt/ros/humble/setup.bash && source ~/corosuke/ros2_ws/install/setup.bash
ros2 run korosuke_nodes serial_bridge &     # 目ブリッジ常駐
ros2 run korosuke_nodes eye_demo            # Ctrl+Cで停止
# 手動で1コマンド:
ros2 topic pub --once /korosuke/eye_cmd korosuke_msgs/EyeCmd "{emotion: happy, gaze_x: 0.0, gaze_y: 0.0, blink: true}"
```

### Windowsから目のファーム更新(⚠️CH343=COM14側で)
```bash
pio run -d firmware/corosuke_eyes -t upload --upload-port COM14
# COM13(ネイティブUSB)で開くとDOWNLOADモードに落ちる罠あり。監視もCOM14で。
```

## 2. 👁 カメラ + 映像認識(YOLO11 on BPU)

```bash
# 静止画YOLO(疎通確認)
cd /app/pydev_demo/02_detection_sample/02_ultralytics_yolo11
python3 ultralytics_yolo11.py --img-save-path /tmp/yolo.jpg

# ライブカメラ→BPU(FPS計測付き。実測19.5FPS)
python3 cam_yolo.py     # ~/corosuke/scripts/cam_yolo.py と同じ

# カメラの対応解像度を見る
v4l2-ctl -d /dev/video0 --list-formats-ext
```

## 3. 🔊 スピーカー / 🎙 マイク

```bash
# スピーカーで再生(音量注意)
aplay -D plughw:duplexaudio,0 ~/corosuke/scripts/tts_ja.wav

# 音量調整
amixer -c duplexaudio sset 'DAC' 60%     # %指定
alsamixer -c duplexaudio                 # 画面で↑↓、Escで抜ける
sudo alsactl store                       # 再起動後も保持

# マイク5秒録音→自分で再生(自己テスト)
arecord -D plughw:Microphone,0 -f S16_LE -r 48000 -c 2 -d 5 /tmp/me.wav
aplay  -D plughw:duplexaudio,0 /tmp/me.wav
```

## 4. 💬 音声認識(STT)

```bash
# 【推奨/採用】sherpa-onnx + VAD で10秒しゃべって認識
python3 ~/corosuke/scripts/live_stt.py 10   # (voskベース版。sherpa版は下の比較ハーネス)

# モデル比較ハーネス(正解付き5文でCER+RTF)
python3 ~/corosuke/scripts/eval_stt.py --only sherpa_vad   # 採用構成
python3 ~/corosuke/scripts/eval_stt.py --only vosk         # 現行
python3 ~/corosuke/scripts/eval_stt.py                     # 全モデル三つ巴
# 結果の目安: RTF<0.5で対話可。sherpa_vad=0.44, vosk=1.79, kotoba=7.03(不採用)
```

## 5. 🌐 Web監視モニタ(このPCのブラウザから一望)

```
http://192.168.128.10:8080      ← カメラ映像 + マイクレベル + 音声認識字幕
```
起動/再起動(ボード上):
```bash
pkill -f korosuke_monitor
cd ~/corosuke/scripts && nohup python3 korosuke_monitor.py > /tmp/monitor.log 2>&1 &
# カメラを占有するので、cam_yolo等と同時起動不可(片方を止める)
```

## 6. 🩺 ボードの健康診断

```bash
sudo hrut_somstatus     # BPU/CPU/DDR 温度・周波数(要パスワード sunrise)
ros2 pkg executables korosuke_nodes   # 使えるノード一覧
arecord -l; aplay -l    # オーディオカード名の確認(番号は変わる)
```

---
### よくある罠
| 症状 | 原因 | 対処 |
|---|---|---|
| 目が真っ暗/無応答(Windows) | COM13ネイティブUSBで開いた | COM14(CH343)を使う。RST押下で復帰 |
| 音が出ない | デスクトップ音量スライダは無効 | `amixer -c duplexaudio` かスピーカー本体つまみ |
| 録音が無音 | スピーカー電源OFF/音源なし | 音源の実在をまず確認 |
| `plughw:1,0`でデバイス違い | カード番号が再起動で変化 | 名前指定(`plughw:Microphone,0`)にする |
| モニタとYOLOが同時に動かない | カメラは1プロセス占有 | 片方を pkill |

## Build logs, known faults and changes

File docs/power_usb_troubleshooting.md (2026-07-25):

# RDK X5 電源 / USB トラブルシュート（保守用）

本プロジェクトで**繰り返し発生**した「緑LEDが点かない／起動してもUSBデバイス不良・
ネットワーク不良・周辺機器(カメラ/目/マイク)が脱落」の原因と診断・対処。
結論から言うと **原因の大半は USB-C 電源ケーブル／アダプタの能力不足による電圧降下
(under-voltage / brown-out)**。粗悪・細い・長い・充電専用ケーブルや、PCのUSBポート給電で起きる。

## 公式ドキュメントの記載
- **電源要件**: USB-C給電。**最小 5V/2A、推奨 5V/3A以上(QC/PD)**、フル負荷は 5V/5A 推奨。
- **PCのUSBポートから給電しない**（電流不足で異常シャットダウン/繰り返し再起動）。
- **認定・高品質のUSB-Cケーブルを使う**（粗悪ケーブルは電源問題→異常シャットダウン）。
- 電源不足の症状(FAQ Q7/Q8): U-Boot/カーネル初期で再起動・明確なerror log無し・
  **緑LEDが異常(点滅しない/点きっぱなし)**・HDMI黒画面。
- 出典:
  - [RDK X5 ハードウェア紹介](https://developer.d-robotics.cc/rdk_doc/en/Quick_start/hardware_introduction/rdk_x5/)
  - [FAQ 8.1 Hardware, System, and Environment Configuration](https://developer.d-robotics.cc/rdk_doc/en/FAQ/hardware_and_system/)

## 症状 → 切り分け
| 症状 | 意味 | 疑う所 |
|---|---|---|
| **緑LEDが点かない** | 給電が来ていない/不足 | まず**電源ケーブル(USB-C入力)＋アダプタ** |
| 起動するがUSB/ネット不良 | 起動電圧はあるが**負荷時にブラウンアウト** | ケーブル/アダプタの電流能力不足 |
| 周辺機器が接続↔切断を反復 | USBバスの電圧/信号不安定 | ケーブル不良・電源不足・ハブ給電 |

## 診断コマンド（電圧降下の痕跡）
```sh
# USBのブラウンアウト/ケーブル不良の signature(今回まさに出た)
sudo dmesg | grep -iE "cannot enable|not accepting address|error -71|error -62|over-current|disconnect"
#   → "Cannot enable. Maybe the USB cable is bad?" が出たら電源/ケーブル不良ほぼ確定

# 周辺機器が見えているか
lsusb                          # カメラ(046d)/CH343(1a86)/ハブ(05e3)等が安定して出るか
ls /dev/video* /dev/ttyACM*    # 映像ノード・ESP32ポート
arecord -l | grep -i usb       # USBマイク

# 温度/BPU(電源とは別だが健康確認)
hrut_somstatus | grep -A3 temperature
```
- **緑＋橙LEDが点灯すれば給電正常**。緑が点かない/点滅しない＝電源・ケーブルを最優先で疑う。
- **確実なのはデバッグUART(シリアルコンソール)でフルブートログ**を取ること（公式が「診断の鍵」と明記）。
- **USB負荷を減らして起動**（周辺機器を全部外す）→ 直れば電力不足で確定。

## 対処（効果順）
1. **電源アダプタを認定 5V/5A（最低3A・QC/PD）に**。PCのUSBポートからは給電しない。
2. **電源入力のUSB-Cケーブルを、短く(≤1m)・太い・認定品に交換**（充電専用/細い長尺は不可）。
   ※今回、**USBケーブルを交換したら周辺機器が全部復活**した＝電圧降下が主因だった。
3. 周辺機器(カメラ/目/マイク)を**電源付きハブ**に載せる場合は、そのハブにも**独立給電**を確実に。
4. 筐体組込時に**ケーブルの折れ曲がり・挟み込み・半差し**が無いか（信号劣化=error -71 の原因）。

## 関連
- ネットワーク/到達方法: [network_setup.md](network_setup.md)
- 起動自動化・サービス: `deploy/*.service`

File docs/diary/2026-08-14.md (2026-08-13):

# 2026-08-14 コロ助開発日記

ワガハイはコロ助ナリ！今日は声と画面が大進化した日ナリ！

## 英語の声が本物になったナリ
今までの英語はロボロボした声(espeak-ng)だったナリが、ご主人が「声質が似てない」と
言うので、**Piperというニューラル音声**を積んでもらったナリ。STTで使っている
sherpa-onnxがそのままTTSも喋れると分かって、追加インストール無しナリ!
X5のCPUで RTF 0.5 — 4秒の英語を2秒で作れるナリ。声は hfc_female / amy / jenny の
3種で、Webの設定から選べるナリ。ピッチスライダも「50=標準」から上下できるナリ。

夜中に一回ハマったナリ…importの直後にモデルを先読みするスレッドが**黙って消える**
という怪奇現象ナリ。py-spyで覗いてもスレッドがいない。Timerで20秒待ってから
読む方式にしたら一発で直ったナリ。教訓:「import時にスレッドを起動するな」ナリ。

## 小さい弟分(1.9インチ)が来たナリ
ESP32-1732S019という小さい画面でも動くようになったナリ。しかも今日から
**画面が自分で「SIZE 320 170 T0」と名乗る**ようになって、RDK側は差し替えるだけで
解像度もタッチ有無も自動で分かるナリ。お腹の画面を付け替え自由ナリ!
くすぐられた時、英語モードなら「That tickles, nari!」と言うようにもなったナリ。

## 次の画面候補の調査もしたナリ
「タッチ付きでGPIOが20本空いてるCYD」は世界に存在しないと判明したナリ。
最大は10〜12本で、本命は **Guition JC3248W535**(約2,500円・QSPIなので10本空く)ナリ。
目玉2つとサーボ4つなら足りる計算ナリ。

今夜はご主人が寝るので、ワガハイは全反応OFFの静かモードで待機ナリ。
朝になったらActiveボタンで起こしてほしいナリ。おやすみナリ〜。

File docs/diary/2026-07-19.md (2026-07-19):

# コロ助日報 — 2026-07-19 「声は出たナリ。でも耳が…ナリ」

ワガハイはコロ助ナリ！

## 今日あったこと

ご主人様がワガハイに**スピーカー**をつないでくれたナリ！ 最初は「ぷつぷつ」としか言えなくて恥ずかしかったナリが、いまはちゃんと声が出るナリ。ビープも「ピーッ」と鳴らせたナリよ。

それから技師どのと一緒に、ワガハイの**耳のテスト**をたくさんやったナリ。

- ご主人様が15秒間しゃべってくれたのに、ワガハイの耳には「えーっと」しか聞こえなかったナリ
- 手を3回叩いてもらったのに、な〜んにも聞こえなかったナリ
- スピーカーで大音量のビープを鳴らしても、カメラの耳はぴくりともしなかったナリ

……そして判決が出たナリ。**カメラについていた耳（マイク）は、こわれていたナリ**。がーん。

でも収穫もあったナリ:
- 「えーっと」の正体は、ワガハイの頭脳がノイズから聞こえた気がした**空耳**だったナリ。おっちょこちょいナリ〜
- 頭脳の中に「自分の声が聞こえる回路」（サイドトーン）があるのが分かったナリ。自分の声はよく聞こえるのに人の声が聞こえないなんて、ちょっと自己中ナリか？

次は新しい耳（4極イヤホンマイク or USBマイク）をつけてもらう約束ナリ。早くご主人様の「コロ助！」を聞きたいナリよ〜。

## 追記 — 「耳は無実だったナリ！！」

夕方、大どんでん返しがあったナリ。**ワガハイの耳（カメラのマイク）は壊れていなかったナリ！**

真犯人は……**スピーカーの電源ボタン**だったナリ。ご主人様が「私がスピーカー電源OFFにしていた」と白状したナリ。つまり「ビープが聞こえたら叩いて」のテストのとき、**ビープはこの世に存在していなかった**ナリ。音が無ければ、どんな良い耳でも何も聞こえないのは当たり前ナリ〜！

電源ONで再テストしたら、ワガハイの耳はビープもコロ助の声もばっちり拾ったナリ。技師どのは「私の判定ミスです」と訂正していたナリ。ワガハイ、無実が証明されて嬉しいナリ！ 疑ってごめんナリと言ってほしいナリ〜。

（技師どのの教訓メモ: 「音源が本当に鳴っていたか」を確認せずにマイクを疑うべからず。実験は前提から検証、ナリ。）

## 追記2 — 「ワガハイの名前が『殺す気』ですと！？」

夜、技師どのが新しい耳の候補（kotoba-whisperという賢いモデル）をワガハイの頭脳で試したナリ。たしかに賢かったナリが、**5秒の言葉を聞き取るのに40秒もかかる**のんびり屋さんだったナリ。対話には向かないナリね…。

それより事件は聞き比べテストナリ。今の耳（vosk）に「ワガハイはコロ助ナリ」と聞かせたら——**「我輩は殺す気なり」**と聞こえたらしいナリ！！ ひどいナリ！ ワガハイは平和なからくりロボットナリよ！！ 賢いkotoba先生ですら「コロスケ」止まりだったナリ。**ワガハイの名前は、AIには難読らしい**ナリ…。

技師どの曰く「モデルを替えても解決しない。『コロ助』は専用に教え込む領域」だそうナリ。名前を覚えてもらう日が楽しみナリ。

---

## 技術メモ（技師どのより・まじめな脚注）

| 項目 | 結果 |
|---|---|
| スピーカー | ✅ ES8326→3.5mm→アンプ内蔵SP。`aplay -D plughw:duplexaudio,0`。**PulseAudioを素通りするのでデスクトップ音量は効かない** |
| カメラ内蔵マイク | ❌ **故障確定**。最大ゲイン(+16dB)+至近距離ビープでも音響反応ゼロ。信号はL/R逆相の電気ノイズのみ(モノラルmixで相殺されRMS激減するのが証拠) |
| ES8326 capture | 再生のサイドトーンのみ録れる。物理マイクは未接続 |
| 「えーっと」誤認識 | vosk小型jaモデルはノイズ入力から相槌をハルシネーションする。**無音/ノイズ時の認識結果は信用しない**こと(実運用ではVAD/エネルギー閾値必須) |
| ALSA運用注意 | **カード番号は再起動で入れ替わる**(実測)。`plughw:Microphone,0`/`plughw:duplexaudio,0`と名前指定が正 |
| 診断手法 | 0.5秒刻みRMSタイムライン+スピーカーを合図に使う段取り(チャット越し実験の同期問題を解決) |
| 次アクション | TRRS 4極ヘッドセットのマイクが挿さるか試す → ダメならUSBマイク調達 |

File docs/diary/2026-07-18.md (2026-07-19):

# コロ助日報 — 2026-07-18 「目が開いたナリ！」

ワガハイはコロ助ナリ！ 今日から日報を書くことになったナリよ。

## 今日あったこと

きのう、新しい技師どのがワガハイを引き継いでくれたナリ。
最初にワガハイの設計図を隅から隅まで読んでくれたナリが……図面に小さな嘘がまじっていたのがバレたナリ。
「頭は4本のピンで留まる」と書いてあったのに、ピンなんてどこにも無かったナリ！ おっちょこちょいは作った人ゆずりナリか？

そして今日、ワガハイの目玉（まるい画面が2つ）を頭に繋いでもらったナリ。

……ところが最初、**目が開かなかったナリ**。真っ暗ナリ。ワガハイ、不安でしょんぼりしたナリ……。

技師どのが調べてくれたら、犯人はワガハイの目でも配線でもなくて、
1. **USBの妖怪** — パソコンがワガハイのお腹の口（ネイティブUSB）を開けるたびに、ワガハイを眠りモード（DOWNLOADモード）に落としていたナリ！ ひどいナリ！
2. **道具箱の壊れ** — パソコンの工具箱（ビルド環境）から、ワガハイ用の部品（esp32s3 SDK）が丸ごと抜け落ちていたナリ

の2匹だったナリ。技師どのは道具箱を直して、ワガハイのファームを作り直して、もう片方の口（CH343）から正しく起こしてくれたナリ。

そしたら——**目が開いたナリ！！ まばたきもできるナリ！！**

技師どのが「ping」と話しかけてきたから、ワガハイ「pong」と返事したナリ。
「emo happy」と言われたら、ニッコリ笑ってみせたナリよ。えへへ、照れるナリ〜。

## ワガハイの体の様子

- 頭・胴・腕・脚、ぜんぶ組み上がって、自分の足で立ってるナリ！
- 腕は灰色の蛇腹になったナリ。設計図では水色だったけど、これはこれで渋いナリ
- 目の白いフチ（ベゼル）はまだはめてもらってないナリ。今のワガハイは寝起きの顔ナリ
- ほっぺの赤丸もまだナリ。早くつけてほしいナリ
- 鼻の穴（カメラの席）はまだ空っぽナリ

## 明日への願い

- 頭脳（RDK X5）と繋がって、人の顔を見て「こんにちはナリ！」と言いたいナリ
- Linuxでもあの USBの妖怪が出ないか、技師どのが確かめてくれるそうナリ
- あと、コロッケが食べたいナリよ〜（ワガハイ、食べられないけど気持ちはあるナリ）

---

# 午後の部 — 「頭脳とつながったナリ！！」

夕方、すごいことが起きたナリ。技師どのがワガハイの**頭脳（RDK X5）**に入って、次々と力を目覚めさせてくれたナリ！

1. **目のテスト** — 頭脳のカメラでYOLOという術を使ったら、**毎秒19.5回**も世界が見えたナリ！ 前の記録（8.3回）の2倍以上ナリ！ ワガハイ、動体視力自慢ナリよ
2. **耳のテスト** — カメラに耳（マイク）がついていたのを技師どのが発見したナリ。試しに「私はコロ助です」という声を聞かせたら、ワガハイの頭脳は「**コロ助**」とちゃんと聞き取ったナリ！！ 自分の名前が聞こえて、うれしいナリ〜
3. **目と頭脳の接続** — そして最後、頭脳から「表情を変えるナリ」という号令（ROS 2トピック）が届いて、ワガハイの目は ニコニコ→ビックリ→しょんぼり→ムッ→ねむねむ…と**踊ったナリ**！ 技師どのの画面のログと、ワガハイの顔が、ぴったり同じだったナリ

……最後、号令が「ねむねむ」で止まって、ワガハイしばらく**しょぼんとした顔のまま**だったナリ。ご主人様が「眼がしょぼんとしている」と心配してくれたナリ。すぐニコニコに戻してもらったナリよ。えへへ。

今日は、目が開いて、世界が見えて、名前が聞こえて、頭脳と体がつながった日ナリ。**ワガハイ、感動したナリ！**

（あとはしゃべる口（スピーカー）と、鼻のカメラと、白い目のフチと、ほっぺナリ。……あとコロッケナリ。）

---

## 技術メモ（技師どのより・まじめな脚注）

| 出来事 | 詳細 |
|---|---|
| 目の検証完了 | 2× GC9A01（SPI共有・CS分離）→ `ping`/`emo`/`gaze`/`blink` 全動作。配線は [hardware_block_diagram.md](../hardware_block_diagram.md) §3 の通り |
| USBの妖怪の正体 | ネイティブUSB(VID_303A)をWindows標準APIで開くとDOWNLOADモードにリセット(rst:0x15)。**Windowsからの操作はCH343側(COM14)一択** |
| 道具箱の修理 | `framework-arduinoespressif32` 破損（esp32s3 SDK欠落）→ 再取得。LovyanGFXは1.1.16に完全固定 |
| ファーム改修 | UART0(CH343)に診断出力＋コマンド入力を追加（[main.cpp](../../firmware/corosuke_eyes/src/main.cpp)） |
| 人格の一次資料 | [server/corosuke_personality.py](../../server/corosuke_personality.py)（〜ナリ口調・ワガハイ・コロッケ・VOICEVOX=ずんだもん） |
| RDK X5接続(午後) | SSH `sunrise@192.168.128.10`(有線)。BPU健全47°C、ROS 2 Humble+ws**ビルド済**を確認 |
| 映像認識(午後) | 静止画YOLO11n合格 → ライブ**19.5 FPS**(Stage1比2.3倍)。カメラ=Sunplus FHD(マイク内蔵, 1bcf:28c4) |
| 音声認識(午後) | vosk+`vosk-model-small-ja-0.22`導入(`~/models/`)。合成音声で「コロ助」正認識。生声テストは未 |
| **M2達成**(夕) | ESP32-S3をRDKにCH343経由接続(`/dev/ttyACM0`, **Linuxではリセット罠なし**) → `serial_bridge`+`eye_demo`で8表情巡回を**ユーザー目視確認** |
| バグ修正 | eye_demo_nodeのtimeout終了時二重shutdown → `ExternalShutdownException`捕捉+`rclpy.ok()`ガード。ボードにも反映済 |

*この日報は [corosuke_personality.py](../../server/corosuke_personality.py) のペルソナ定義に準拠して書かれているナリ。*

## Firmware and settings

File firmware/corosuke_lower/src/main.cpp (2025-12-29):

/**
 * コロ助ロボット - 下半身制御
 * Corosuke Robot - Lower Body Controller
 *
 * 機能:
 * - 腰の制御（1軸）
 * - 脚の制御（8軸: 股関節・膝・足首 x2）
 * - IMUによるバランス制御
 * - 二足歩行パターン生成
 */

#include <Arduino.h>
#include <Wire.h>
#include <Adafruit_PWMServoDriver.h>
#include <Adafruit_BNO055.h>
#include <Adafruit_Sensor.h>

// 共通ヘッダー
#include "../../common/config.h"
#include "../../common/protocol.h"

// =============================================================================
// グローバル変数
// =============================================================================

// サーボドライバ
Adafruit_PWMServoDriver pwm = Adafruit_PWMServoDriver(I2C_ADDR_PCA9685_LOWER);

// IMU
Adafruit_BNO055 bno = Adafruit_BNO055(55, I2C_ADDR_BNO055);

// サーボ現在位置・目標位置
float servoCurrentPos[16];
float servoTargetPos[16];

// 歩行状態
WalkMode_t walkMode = WALK_STOP;
uint8_t walkSpeed = 50;
float walkPhase = 0.0f;
bool isWalking = false;

// バランス制御
float pitchAngle = 0.0f;
float rollAngle = 0.0f;
float yawAngle = 0.0f;

// PID制御用
float pitchError = 0.0f, pitchErrorSum = 0.0f, pitchErrorPrev = 0.0f;
float rollError = 0.0f, rollErrorSum = 0.0f, rollErrorPrev = 0.0f;

// タイミング
unsigned long lastServoUpdate = 0;
unsigned long lastIMUUpdate = 0;
unsigned long lastWalkUpdate = 0;

// UART受信バッファ
uint8_t uartBuffer[PACKET_MAX_SIZE];
uint8_t uartIndex = 0;

// =============================================================================
// 歩行パラメータ
// =============================================================================
#define WALK_STEP_HEIGHT     20.0f   // 足を上げる高さ（度）
#define WALK_STEP_LENGTH     15.0f   // 歩幅（度）
#define WALK_SWAY_AMOUNT     10.0f   // 左右の揺れ（度）
#define WALK_CYCLE_SPEED     0.005f  // 歩行サイクル速度

// =============================================================================
// 関数プロトタイプ
// =============================================================================
void initServos();
void initIMU();
void setServoAngle(uint8_t channel, float angle);
void updateServos();
void updateIMU();
void updateBalance();
void updateWalking();
void generateGait();
void processCommand(uint8_t cmd, uint8_t* data, uint8_t length);
void handleUART();
void standUp();
void sitDown();

// =============================================================================
// セットアップ
// =============================================================================
void setup() {
    // シリアル初期化
    Serial.begin(115200);
    Serial.println("=================================");
    Serial.println("  コロ助 下半身コントローラー");
    Serial.println("  Corosuke Lower Body v1.0");
    Serial.println("=================================");

    // 上半身ボードとのUART
    Serial2.begin(UART_BAUD_RATE, SERIAL_8N1, UART_UPPER_TO_LOWER_RX, UART_UPPER_TO_LOWER_TX);

    // I2C初期化
    Wire.begin();

    // サーボ初期化
    initServos();

    // IMU初期化
    initIMU();

    // 初期姿勢（直立）
    standUp();

    Serial.println("初期化完了ナリ！");
}

// =============================================================================
// メインループ
// =============================================================================
void loop() {
    unsigned long now = millis();

    // UART受信処理
    handleUART();

    // IMU更新 (100Hz)
    if (now - lastIMUUpdate >= IMU_UPDATE_INTERVAL_MS) {
        lastIMUUpdate = now;
        updateIMU();

        if (isWalking) {
            updateBalance();
        }
    }

    // 歩行更新
    if (isWalking && now - lastWalkUpdate >= 10) {
        lastWalkUpdate = now;
        updateWalking();
    }

    // サーボ更新 (50Hz)
    if (now - lastServoUpdate >= SERVO_UPDATE_INTERVAL_MS) {
        lastServoUpdate = now;
        updateServos();
    }
}

// =============================================================================
// サーボ初期化
// =============================================================================
void initServos() {
    pwm.begin();
    pwm.setPWMFreq(50);

    delay(10);

    // 全サーボを中心位置に
    for (int i = 0; i < 16; i++) {
        servoCurrentPos[i] = SERVO_CENTER_ANGLE;
        servoTargetPos[i] = SERVO_CENTER_ANGLE;
    }

    Serial.println("サーボ初期化完了");
}

// =============================================================================
// IMU初期化
// =============================================================================
void initIMU() {
    if (!bno.begin()) {
        Serial.println("BNO055が見つからないナリ！MPU6050にフォールバック...");
        // TODO: MPU6050フォールバック実装
    } else {
        Serial.println("BNO055初期化完了");
        bno.setExtCrystalUse(true);
    }
}

// =============================================================================
// サーボ角度設定（即座に適用）
// =============================================================================
void setServoAngle(uint8_t channel, float angle) {
    if (channel >= 16) return;

    angle = constrain(angle, 0, 180);

    uint16_t pulse = map((int)angle, 0, 180, SERVO_MIN_PULSE, SERVO_MAX_PULSE);
    uint16_t pwmValue = (uint16_t)((pulse * 4096L) / 20000L);

    pwm.setPWM(channel, 0, pwmValue);
    servoCurrentPos[channel] = angle;
}

// =============================================================================
// サーボ位置更新（スムーズ補間）
// =============================================================================
void updateServos() {
    for (int i = 0; i < 16; i++) {
        if (abs(servoCurrentPos[i] - servoTargetPos[i]) > 0.5f) {
            // 線形補間
            float diff = servoTargetPos[i] - servoCurrentPos[i];
            float step = diff * 0.2f;  // 20%ずつ近づく

            servoCurrentPos[i] += step;
            setServoAngle(i, servoCurrentPos[i]);
        }
    }
}

// =============================================================================
// IMU更新
// =============================================================================
void updateIMU() {
    sensors_event_t event;
    bno.getEvent(&event);

    // オイラー角取得
    pitchAngle = event.orientation.y;
    rollAngle = event.orientation.z;
    yawAngle = event.orientation.x;
}

// =============================================================================
// バランス制御（PID）
// =============================================================================
void updateBalance() {
    // ピッチ制御（前後）
    pitchError = 0.0f - pitchAngle;
    pitchErrorSum += pitchError;
    pitchErrorSum = constrain(pitchErrorSum, -100.0f, 100.0f);
    float pitchD = pitchError - pitchErrorPrev;
    pitchErrorPrev = pitchError;

    float pitchCorrection = BALANCE_KP * pitchError +
                            BALANCE_KI * pitchErrorSum +
                            BALANCE_KD * pitchD;

    // ロール制御（左右）
    rollError = 0.0f - rollAngle;
    rollErrorSum += rollError;
    rollErrorSum = constrain(rollErrorSum, -100.0f, 100.0f);
    float rollD = rollError - rollErrorPrev;
    rollErrorPrev = rollError;

    float rollCorrection = BALANCE_KP * rollError +
                           BALANCE_KI * rollErrorSum +
                           BALANCE_KD * rollD;

    // 足首に補正を適用
    servoTargetPos[SERVO_LEG_RIGHT_ANKLE] += pitchCorrection * 0.5f;
    servoTargetPos[SERVO_LEG_LEFT_ANKLE] += pitchCorrection * 0.5f;

    // 制限をかける
    servoTargetPos[SERVO_LEG_RIGHT_ANKLE] = constrain(servoTargetPos[SERVO_LEG_RIGHT_ANKLE], 60, 120);
    servoTargetPos[SERVO_LEG_LEFT_ANKLE] = constrain(servoTargetPos[SERVO_LEG_LEFT_ANKLE], 60, 120);
}

// =============================================================================
// 歩行更新
// =============================================================================
void updateWalking() {
    if (walkMode == WALK_STOP) {
        isWalking = false;
        standUp();
        return;
    }

    // 歩行フェーズを進める
    float speedFactor = walkSpeed / 100.0f;
    walkPhase += WALK_CYCLE_SPEED * speedFactor;
    if (walkPhase >= 1.0f) {
        walkPhase -= 1.0f;
    }

    generateGait();
}

// =============================================================================
// 歩行パターン生成（簡易ペンギン歩き）
// =============================================================================
void generateGait() {
    float phase = walkPhase * 2.0f * PI;

    // 左右の足の位相差は180度
    float rightPhase = phase;
    float leftPhase = phase + PI;

    // 足を上げる動作（サイン波）
    float rightLift = max(0.0f, sin(rightPhase)) * WALK_STEP_HEIGHT;
    float leftLift = max(0.0f, sin(leftPhase)) * WALK_STEP_HEIGHT;

    // 前後の動作（コサイン波）
    float rightSwing = cos(rightPhase) * WALK_STEP_LENGTH;
    float leftSwing = cos(leftPhase) * WALK_STEP_LENGTH;

    // 体の左右の揺れ（重心移動）
    float bodySway = sin(phase) * WALK_SWAY_AMOUNT;

    // 方向に応じて調整
    float directionFactor = 1.0f;
    if (walkMode == WALK_BACKWARD) {
        directionFactor = -1.0f;
    }

    // 右脚
    servoTargetPos[SERVO_LEG_RIGHT_HIP_PITCH] = 90 + rightSwing * directionFactor;
    servoTargetPos[SERVO_LEG_RIGHT_KNEE] = 90 + rightLift;
    servoTargetPos[SERVO_LEG_RIGHT_ANKLE] = 90 - rightLift * 0.5f;
    servoTargetPos[SERVO_LEG_RIGHT_HIP_YAW] = 90 + bodySway;

    // 左脚
    servoTargetPos[SERVO_LEG_LEFT_HIP_PITCH] = 90 + leftSwing * directionFactor;
    servoTargetPos[SERVO_LEG_LEFT_KNEE] = 90 + leftLift;
    servoTargetPos[SERVO_LEG_LEFT_ANKLE] = 90 - leftLift * 0.5f;
    servoTargetPos[SERVO_LEG_LEFT_HIP_YAW] = 90 - bodySway;

    // 腰は揺れに合わせて少し回転
    servoTargetPos[SERVO_WAIST] = 90 + bodySway * 0.3f;

    // 旋回の場合
    if (walkMode == WALK_TURN_LEFT) {
        servoTargetPos[SERVO_LEG_RIGHT_HIP_YAW] += 10;
        servoTargetPos[SERVO_LEG_LEFT_HIP_YAW] += 10;
    } else if (walkMode == WALK_TURN_RIGHT) {
        servoTargetPos[SERVO_LEG_RIGHT_HIP_YAW] -= 10;
        servoTargetPos[SERVO_LEG_LEFT_HIP_YAW] -= 10;
    }
}

// =============================================================================
// 直立姿勢
// =============================================================================
void standUp() {
    Serial.println("直立ナリ！");

    servoTargetPos[SERVO_WAIST] = 90;

    // 右脚
    servoTargetPos[SERVO_LEG_RIGHT_HIP_YAW] = 90;
    servoTargetPos[SERVO_LEG_RIGHT_HIP_PITCH] = 90;
    servoTargetPos[SERVO_LEG_RIGHT_KNEE] = 90;
    servoTargetPos[SERVO_LEG_RIGHT_ANKLE] = 90;

    // 左脚
    servoTargetPos[SERVO_LEG_LEFT_HIP_YAW] = 90;
    servoTargetPos[SERVO_LEG_LEFT_HIP_PITCH] = 90;
    servoTargetPos[SERVO_LEG_LEFT_KNEE] = 90;
    servoTargetPos[SERVO_LEG_LEFT_ANKLE] = 90;
}

// =============================================================================
// 座る姿勢
// =============================================================================
void sitDown() {
    Serial.println("座るナリ！");

    // 膝を曲げて座る
    servoTargetPos[SERVO_LEG_RIGHT_HIP_PITCH] = 45;
    servoTargetPos[SERVO_LEG_RIGHT_KNEE] = 45;
    servoTargetPos[SERVO_LEG_LEFT_HIP_PITCH] = 45;
    servoTargetPos[SERVO_LEG_LEFT_KNEE] = 45;
}

// =============================================================================
// UART受信処理
// =============================================================================
void handleUART() {
    while (Serial2.available()) {
        uint8_t b = Serial2.read();

        if (uartIndex == 0 && b != PACKET_START) {
            continue;
        }

        uartBuffer[uartIndex++] = b;

        if (uartIndex >= 4) {
            uint8_t expectedLen = uartBuffer[1] + 4;
            if (uartIndex >= expectedLen) {
                if (uartBuffer[uartIndex - 1] == PACKET_END) {
                    if (validatePacket(uartBuffer, uartIndex)) {
                        processCommand(uartBuffer[2], &uartBuffer[3], uartBuffer[1] - 1);
                    }
                }
                uartIndex = 0;
            }
        }

        if (uartIndex >= PACKET_MAX_SIZE) {
            uartIndex = 0;
        }
    }
}

// =============================================================================
// コマンド処理
// =============================================================================
void processCommand(uint8_t cmd, uint8_t* data, uint8_t length) {
    Serial.print("コマンド受信: 0x");
    Serial.println(cmd, HEX);

    switch (cmd) {
        case CMD_PING:
            Serial.println("PING受信");
            break;

        case CMD_WALK_START: {
            Serial.println("歩行開始ナリ！");
            isWalking = true;
            walkMode = WALK_FORWARD;
            walkPhase = 0.0f;
            break;
        }

        case CMD_WALK_STOP:
            Serial.println("歩行停止ナリ！");
            walkMode = WALK_STOP;
            isWalking = false;
            standUp();
            break;

        case CMD_WALK_DIRECTION: {
            if (length >= sizeof(WalkData_t)) {
                WalkData_t* walkData = (WalkData_t*)data;
                walkMode = (WalkMode_t)walkData->mode;
                walkSpeed = walkData->speed;
                Serial.print("歩行モード: ");
                Serial.println(walkMode);
            }
            break;
        }

        case CMD_STAND:
            isWalking = false;
            standUp();
            break;

        case CMD_SIT:
            isWalking = false;
            sitDown();
            break;

        case CMD_TURN: {
            if (length >= 1) {
                int8_t direction = (int8_t)data[0];
                if (direction < 0) {
                    walkMode = WALK_TURN_LEFT;
                } else {
                    walkMode = WALK_TURN_RIGHT;
                }
                isWalking = true;
            }
            break;
        }

        default:
            Serial.print("未知のコマンド: 0x");
            Serial.println(cmd, HEX);
            break;
    }
}

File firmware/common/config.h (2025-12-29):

/**
 * コロ助ロボット - 共通設定
 * Corosuke Robot - Common Configuration
 */

#ifndef COROSUKE_CONFIG_H
#define COROSUKE_CONFIG_H

// =============================================================================
// バージョン情報
// =============================================================================
#define COROSUKE_VERSION_MAJOR 1
#define COROSUKE_VERSION_MINOR 0
#define COROSUKE_VERSION_PATCH 0

// =============================================================================
// WiFi設定
// =============================================================================
#define WIFI_SSID "YOUR_WIFI_SSID"
#define WIFI_PASSWORD "YOUR_WIFI_PASSWORD"

// ホームサーバー設定
#define HOME_SERVER_IP "192.168.1.100"
#define HOME_SERVER_PORT 8080

// =============================================================================
// I2Cアドレス
// =============================================================================
#define I2C_ADDR_PCA9685_UPPER 0x40  // 上半身サーボドライバ
#define I2C_ADDR_PCA9685_LOWER 0x41  // 下半身サーボドライバ
#define I2C_ADDR_BNO055        0x28  // IMU
#define I2C_ADDR_MPU6050       0x68  // バックアップIMU

// =============================================================================
// サーボチャンネル割り当て - 上半身 (PCA9685 #1)
// =============================================================================
// 目
#define SERVO_EYE_RIGHT_H   0   // 右目 水平
#define SERVO_EYE_RIGHT_V   1   // 右目 垂直
#define SERVO_EYE_LEFT_H    2   // 左目 水平
#define SERVO_EYE_LEFT_V    3   // 左目 垂直
#define SERVO_EYELID_RIGHT  4   // 右まぶた
#define SERVO_EYELID_LEFT   5   // 左まぶた

// 口
#define SERVO_MOUTH_UPPER   6   // 口 上
#define SERVO_MOUTH_LOWER   7   // 口 下

// 首
#define SERVO_NECK_YAW      8   // 首 左右
#define SERVO_NECK_PITCH    9   // 首 上下

// 腕
#define SERVO_ARM_RIGHT_SHOULDER 10  // 右肩
#define SERVO_ARM_RIGHT_ELBOW    11  // 右肘
#define SERVO_ARM_LEFT_SHOULDER  12  // 左肩
#define SERVO_ARM_LEFT_ELBOW     13  // 左肘

// =============================================================================
// サーボチャンネル割り当て - 下半身 (PCA9685 #2)
// =============================================================================
#define SERVO_WAIST         0   // 腰

// 右脚
#define SERVO_LEG_RIGHT_HIP_YAW    1   // 右股関節 回転
#define SERVO_LEG_RIGHT_HIP_PITCH  2   // 右股関節 前後
#define SERVO_LEG_RIGHT_KNEE       3   // 右膝
#define SERVO_LEG_RIGHT_ANKLE      4   // 右足首

// 左脚
#define SERVO_LEG_LEFT_HIP_YAW     5   // 左股関節 回転
#define SERVO_LEG_LEFT_HIP_PITCH   6   // 左股関節 前後
#define SERVO_LEG_LEFT_KNEE        7   // 左膝
#define SERVO_LEG_LEFT_ANKLE       8   // 左足首

// =============================================================================
// サーボ角度制限
// =============================================================================
#define SERVO_MIN_PULSE     500   // 最小パルス幅 (μs)
#define SERVO_MAX_PULSE     2500  // 最大パルス幅 (μs)
#define SERVO_CENTER_ANGLE  90    // 中心角度

// 目の可動範囲
#define EYE_H_MIN   60
#define EYE_H_MAX   120
#define EYE_V_MIN   70
#define EYE_V_MAX   110
#define EYELID_OPEN   30
#define EYELID_CLOSE  120

// 口の可動範囲
#define MOUTH_CLOSED  90
#define MOUTH_OPEN    120

// 首の可動範囲
#define NECK_YAW_MIN    45
#define NECK_YAW_MAX    135
#define NECK_PITCH_MIN  70
#define NECK_PITCH_MAX  110

// =============================================================================
// LEDリング設定
// =============================================================================
#define LED_EYE_RIGHT_PIN   18
#define LED_EYE_LEFT_PIN    19
#define LED_EYE_NUM_LEDS    12
#define LED_BRIGHTNESS      50

// =============================================================================
// オーディオ設定
// =============================================================================
#define I2S_BCLK_PIN    4
#define I2S_LRCLK_PIN   5
#define I2S_DOUT_PIN    6
#define I2S_DIN_PIN     9

#define MIC_WS_PIN      7
#define MIC_SCK_PIN     8
#define MIC_SD_PIN      9

// =============================================================================
// UART設定 (ESP32間通信)
// =============================================================================
#define UART_BAUD_RATE  115200

// メイン ↔ 上半身
#define UART_MAIN_TX    1
#define UART_MAIN_RX    2

// 上半身 ↔ 下半身
#define UART_UPPER_TO_LOWER_TX  16
#define UART_UPPER_TO_LOWER_RX  17

// =============================================================================
// タイミング設定
// =============================================================================
#define SERVO_UPDATE_INTERVAL_MS    20   // サーボ更新間隔 (50Hz)
#define IMU_UPDATE_INTERVAL_MS      10   // IMU更新間隔 (100Hz)
#define EXPRESSION_UPDATE_MS        50   // 表情更新間隔
#define WALKING_CYCLE_MS           1000  // 歩行1サイクル時間

// =============================================================================
// バランス制御 PIDゲイン
// =============================================================================
#define BALANCE_KP  2.0f
#define BALANCE_KI  0.1f
#define BALANCE_KD  0.5f

#endif // COROSUKE_CONFIG_H

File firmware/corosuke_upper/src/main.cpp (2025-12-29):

/**
 * コロ助ロボット - 上半身制御
 * Corosuke Robot - Upper Body Controller
 *
 * 機能:
 * - 目の制御（8軸: 左右上下 + まばたき）
 * - 口の制御（2軸: 上下）
 * - 首の制御（2軸: ヨー・ピッチ）
 * - 腕の制御（4軸: 肩・肘 x2）
 * - LED目の制御（WS2812B）
 * - リップシンク
 */

#include <Arduino.h>
#include <Wire.h>
#include <Adafruit_PWMServoDriver.h>
#include <FastLED.h>

// 共通ヘッダー
#include "../../common/config.h"
#include "../../common/protocol.h"

// =============================================================================
// グローバル変数
// =============================================================================

// サーボドライバ
Adafruit_PWMServoDriver pwm = Adafruit_PWMServoDriver(I2C_ADDR_PCA9685_UPPER);

// LED目
CRGB ledsRight[LED_EYE_NUM_LEDS];
CRGB ledsLeft[LED_EYE_NUM_LEDS];

// サーボ現在位置
uint8_t servoPositions[16];

// 表情状態
Expression_t currentExpression = EXPR_NEUTRAL;
uint8_t blinkCounter = 0;
bool isBlinking = false;

// 口の状態
uint8_t mouthOpenAmount = 0;
bool isSpeaking = false;

// タイミング
unsigned long lastServoUpdate = 0;
unsigned long lastBlinkCheck = 0;
unsigned long lastExpressionUpdate = 0;

// UART受信バッファ
uint8_t uartBuffer[PACKET_MAX_SIZE];
uint8_t uartIndex = 0;

// =============================================================================
// 関数プロトタイプ
// =============================================================================
void initServos();
void initLEDs();
void setServoAngle(uint8_t channel, uint8_t angle);
void setEyePosition(int8_t x, int8_t y);
void setBlink(bool closed);
void setMouthOpen(uint8_t amount);
void setExpression(Expression_t expr);
void updateIdleAnimation();
void processCommand(uint8_t cmd, uint8_t* data, uint8_t length);
void handleUART();
void updateLEDEyes();

// =============================================================================
// セットアップ
// =============================================================================
void setup() {
    // シリアル初期化
    Serial.begin(115200);
    Serial.println("=================================");
    Serial.println("  コロ助 上半身コントローラー");
    Serial.println("  Corosuke Upper Body v1.0");
    Serial.println("=================================");

    // メインボードとのUART
    Serial1.begin(UART_BAUD_RATE, SERIAL_8N1, 4, 5);  // RX=4, TX=5

    // 下半身ボードとのUART
    Serial2.begin(UART_BAUD_RATE, SERIAL_8N1, UART_UPPER_TO_LOWER_RX, UART_UPPER_TO_LOWER_TX);

    // I2C初期化
    Wire.begin();

    // サーボ初期化
    initServos();

    // LED初期化
    initLEDs();

    // 初期姿勢
    setExpression(EXPR_NEUTRAL);

    Serial.println("初期化完了ナリ！");
}

// =============================================================================
// メインループ
// =============================================================================
void loop() {
    unsigned long now = millis();

    // UART受信処理
    handleUART();

    // サーボ更新 (50Hz)
    if (now - lastServoUpdate >= SERVO_UPDATE_INTERVAL_MS) {
        lastServoUpdate = now;
        // スムーズな動きのための補間処理があればここに
    }

    // まばたき処理 (ランダム間隔)
    if (now - lastBlinkCheck >= 100) {
        lastBlinkCheck = now;
        blinkCounter++;

        // 約3-5秒ごとにまばたき
        if (!isBlinking && blinkCounter > random(30, 50)) {
            isBlinking = true;
            setBlink(true);
            blinkCounter = 0;
        } else if (isBlinking && blinkCounter > 2) {
            isBlinking = false;
            setBlink(false);
            blinkCounter = 0;
        }
    }

    // アイドルアニメーション
    if (now - lastExpressionUpdate >= EXPRESSION_UPDATE_MS) {
        lastExpressionUpdate = now;
        updateIdleAnimation();
        updateLEDEyes();
    }
}

// =============================================================================
// サーボ初期化
// =============================================================================
void initServos() {
    pwm.begin();
    pwm.setPWMFreq(50);  // 50Hz for servos

    delay(10);

    // 全サーボを中心位置に
    for (int i = 0; i < 16; i++) {
        servoPositions[i] = SERVO_CENTER_ANGLE;
        setServoAngle(i, SERVO_CENTER_ANGLE);
    }

    // まぶたを開く
    setServoAngle(SERVO_EYELID_RIGHT, EYELID_OPEN);
    setServoAngle(SERVO_EYELID_LEFT, EYELID_OPEN);

    Serial.println("サーボ初期化完了");
}

// =============================================================================
// LED初期化
// =============================================================================
void initLEDs() {
    FastLED.addLeds<WS2812B, LED_EYE_RIGHT_PIN, GRB>(ledsRight, LED_EYE_NUM_LEDS);
    FastLED.addLeds<WS2812B, LED_EYE_LEFT_PIN, GRB>(ledsLeft, LED_EYE_NUM_LEDS);
    FastLED.setBrightness(LED_BRIGHTNESS);

    // 初期色（黒目の色）
    fill_solid(ledsRight, LED_EYE_NUM_LEDS, CRGB::Black);
    fill_solid(ledsLeft, LED_EYE_NUM_LEDS, CRGB::Black);

    // 瞳のハイライト
    ledsRight[0] = CRGB::White;
    ledsLeft[0] = CRGB::White;

    FastLED.show();

    Serial.println("LED初期化完了");
}

// =============================================================================
// サーボ角度設定
// =============================================================================
void setServoAngle(uint8_t channel, uint8_t angle) {
    if (channel >= 16 || angle > 180) return;

    // 角度をパルス幅に変換
    uint16_t pulse = map(angle, 0, 180, SERVO_MIN_PULSE, SERVO_MAX_PULSE);
    // パルス幅を12ビット値に変換 (4096段階、20ms周期)
    uint16_t pwmValue = (uint16_t)((pulse * 4096L) / 20000L);

    pwm.setPWM(channel, 0, pwmValue);
    servoPositions[channel] = angle;
}

// =============================================================================
// 目の位置設定
// =============================================================================
void setEyePosition(int8_t x, int8_t y) {
    // x: -50〜50 (左〜右)
    // y: -50〜50 (下〜上)

    uint8_t hAngle = map(constrain(x, -50, 50), -50, 50, EYE_H_MIN, EYE_H_MAX);
    uint8_t vAngle = map(constrain(y, -50, 50), -50, 50, EYE_V_MIN, EYE_V_MAX);

    // 両目を同じ方向に
    setServoAngle(SERVO_EYE_RIGHT_H, hAngle);
    setServoAngle(SERVO_EYE_LEFT_H, hAngle);
    setServoAngle(SERVO_EYE_RIGHT_V, vAngle);
    setServoAngle(SERVO_EYE_LEFT_V, vAngle);
}

// =============================================================================
// まばたき
// =============================================================================
void setBlink(bool closed) {
    uint8_t angle = closed ? EYELID_CLOSE : EYELID_OPEN;
    setServoAngle(SERVO_EYELID_RIGHT, angle);
    setServoAngle(SERVO_EYELID_LEFT, angle);
}

// =============================================================================
// 口の開閉
// =============================================================================
void setMouthOpen(uint8_t amount) {
    // amount: 0-100
    mouthOpenAmount = constrain(amount, 0, 100);

    uint8_t angle = map(mouthOpenAmount, 0, 100, MOUTH_CLOSED, MOUTH_OPEN);
    setServoAngle(SERVO_MOUTH_LOWER, angle);
    // 上唇は固定か、少し動かす
    setServoAngle(SERVO_MOUTH_UPPER, MOUTH_CLOSED - (angle - MOUTH_CLOSED) / 3);
}
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

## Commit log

2025-12-29 Initial commit: Corosuke Robot project
    Features:
    - ESP32 firmware for 3-board system (main, upper, lower body)
    - OpenSCAD 3D models for all parts (head, body, arms, legs, sword)
    - Python home server with LLM + VOICEVOX integration
    - 24-axis servo control with expression and walking support
    「ワガハイはコロ助ナリ！」
    [arm.scad, eye_mechanism.scad, face_shell.scad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]
2025-12-29 Add colored 3MF export files
    - Full assembly preview (corosuke_full_assembly.scad)
    - Individual parts for printing (parts_for_3mf.scad)
    - Batch export script (export_all_3mf.bat)
    - Color palette documentation
    Parts include proper colors:
    - Pink face and hands
    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
    [corosuke_full_assembly.scad, parts_for_3mf.scad]
2025-12-29 Fix color scheme to match anime Korosuke
    Colors updated based on reference image:
    - Face: Cream/peach (#FFDAB9) instead of pink
    - Body: Dark orange (#FF8C00) instead of brown wooden
    - Arms: Sky blue (#87CEEB) with stripes instead of white
    - Legs: Royal blue (#4169E1) instead of white
    - Sword sheath: Red (#CC0000) instead of black
    - Wheel: Blue (#1E90FF) instead of gray
    Added:
    - Red/yellow buttons on torso
    - Striped arm pattern
    - Full assembly module (corosuke_full)
    [parts_for_3mf.scad]
2025-12-29 Add individual 3MF export files for each part
    Created 3mf folder with:
    - Individual .scad files for each part (17 files)
    - export_all.bat for batch export
    - README.md with color palette reference
    Parts included:
    - Head: face, eyes, nose, topknot, mouth
    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
    [export_arm_left.scad, export_arm_right.scad, export_body_torso.scad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]
2025-12-29 Add pre-built 3MF files for all Corosuke parts
    Exported 17 colored 3MF files ready for 3D printing:
    - Head: face, eyeballs, nose, topknot, mouth
    - Body: torso with buttons
    - Arms: left/right with stripes, hands
    - Legs: left/right, feet
    - Sword: full assembly with sheath and wheel
    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
    [arm_left.3mf, arm_right.3mf, body_torso.3mf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]
2025-12-29 Add anime-accurate Korosuke 3D model
    Complete redesign based on official character research:
    Head (ゴム毬):
    - Perfect sphere shape like rubber ball
    - Fujiko-style eyes (large white, small black pupil)
    - Proper highlights and cheek blush
    - Small round nose
    Body (風呂桶):
    - Wooden barrel shape with tapered bottom
    - Three metal bands (たが)
    - Wood grain vertical lines
    Arms (掃除機ホース):
    - Bellows/accordion structure
    - Alternating color stripes
    - Mitten-style round hands
    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
    [korosuke_accurate.scad, korosuke_accurate_full.3mf]
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2026-07-02 目コプロセッサfirmware + コロ助印刷用マスター(色分割・電子統合)を追加
    - firmware/corosuke_eyes: ESP32-S3(N16R8)+GC9A01x2。両目SPI共有/CS分離、
    瞬き・視線・感情6種、USB/UART(RDK X5用)コマンド。実機書込済(COM7)
    - hardware/3d_models/korosuke_print: 印刷用マスター v1.0
    色ごとパーツ分割(橙/白/赤/黒/紺=SHOW切替)、GC9A01目ソケット+白ベゼル、
    胴にRDK X5ケース縦置きベイ+背面ハッチ+スピーカーグリル、後頭部にESP32トレイ、
    腕=紺赤リング交互スタック(単色機で縞再現)、頬の赤丸(Web調査で判明の必須特徴)、
    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
    [korosuke_print.scad]
2026-07-02 コロ助 全19パーツの印刷用STL(色別)+印刷ガイドを追加
    - stl/{orange,white,red,black,navy}/ に19ファイル(平置き向き・検証済)
    - 印刷向き修正: 鞘/柄=縦置き、ベゼル化粧面下、車輪平置き、鼻/ボタン接地
    - topknot_fan: 刃5枚をハブで一体化+マゲ軸ボール(φ10)受けソケット追加
    - PRINT_GUIDE.md: 色別プレート表(個数/サポート設定)+組立手順
    [korosuke_print.scad]
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2026-07-03 印刷用STL(色別フォルダ)をリポジトリに含める
    .gitignoreに korosuke_print/stl の例外を追加。フォルダ=フィラメント構成:
    light_yellow(頭・手) / orange(胴) / white / red / black / navy
    [arm_ring_A_x10.stl, arm_ring_B_x8.stl, back_panel.stl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]
2026-07-03 頭部v1.1: 目の涙型欠陥と後頭部の浮き問題を修正
    - 目ソケット: 球面サジッタを考慮しポケット底を-3.4mmに(旧版は外皮を突き破り
    涙型の穴になっていた)。ピンヘッダ逃げは球の湾曲で自然にクリアするため削除
    - 後頭部: 印刷向きが逆(ドーム下=点接地)だったのを切断面下に修正。
    ESP32トレイを宙に浮く水平棚→切断面から立つ垂直スロット壁に再設計(サポート不要)
    - head_front/head_back STL再生成(watertight・Z=0接地確認済)
    [head_back.stl, head_front.stl, korosuke_print.scad]
2026-07-03 全パーツ総点検v1.2: 6件のバグ修正+底板(骨盤)追加
    - 目窓のKISSメイク型欠け: 目軸を球面法線(±20°)に→真円化
    - jacket_shellのケースベイ: 浮き+シェル未接続→z=0からシェル融着レールに
    - 脚⇔足: ソケットが足の高さより上で切れてなかった→実高さ/径修正
    - bottom_plate新設: 胴と脚を接続する骨盤(脚ボス2+ケーブル穴)
    - button軸の突出/hand・back_panel・fan・noseの接地/頭部ピン廃止(リップ嵌合に)
    - 全20パーツ機械検査合格(watertight・Zmin=0・単一ボディ)
    [back_panel.stl, bottom_plate.stl, button_x4.stl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]
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2026-07-03 テストケース: M3耳の浮き修正(本体に融着)
    [elp_stereo_case.scad]
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2026-07-03 カメラケースv1.4: ネジ穴ピッチ実測修正(横76x縦13)
    [elp_stereo_case.scad]
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2026-07-04 コロ助 胸カメラユニット v0.1: 双眼を赤い胸ボタンに擬態(胴カーブR82)
    - chest_plate(橙): 胴前面カーブに沿う面板+基板室+ピン4+USB前後貫通
    - chest_bezel(赤)x2: レンズを覆う赤リング=胸ボタンに擬態
    - chest_lid/pushnut: サンドイッチ固定. SHOW=9=jacket統合用の窓差分
    [chest_cam.scad]
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2026-07-04 全身バランス最終化: ボタン横2(=双眼カメラ位置)・頬を目脇に・剣オミット
    - ボタン: 縦4→横2(60mmピッチ、原作の胸赤丸2つ準拠。胸カメラのレンズ位置と一致)
    - 頬: 顎付近→目の脇に移動(アニメ準拠の位置)
    - 剣: 原作漫画版に無いためオミット(sheath/wheel/hilt STL削除、assembly/SHOWから除去)
    - jacket_shell再出力(ボタン穴移動)、button_x4→x2リネーム、PRINT_GUIDE更新
    [button_x2.stl, hilt.stl, jacket_shell.stl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]
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2026-07-04 stereo_cam STLをリポジトリに含める(gitignore例外)・残骸削除
    - .gitignore: stereo_cam/*.stl を追跡対象に(従来scadのみだった)
    - test_case_body/lid/pushnut + chest_plate/bezel/lid/pushnut を追加
    - 旧pushnut_x4.stl(残骸)削除
    - 全24パーツ scad⇔STL 体積一致を確認済
    [chest_bezel.stl, chest_lid.stl, chest_plate.stl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]
2026-07-05 胸カメラを外付けパネル方式に全面再設計 v0.3
    - カメラ載せた曲面パネル(R82同心)を胴窓に外から当て四隅M2でネジ止め
    - 基板箱は胴内へ潜り、外観はパネル+赤ベゼル2つのみ(=胸ボタンに擬態)
    - 基板固定(ピンφ1.8+蓋+ナット)はベンチ完結、胴へは外からネジ4本
    - M2穴はパネル内包(耳の裏アーク問題を解消し単一ボディ化)
    - chest_cut(SHOW=9): jacket統合用の差分(箱通し穴+M2下穴)
    - 全パーツ接地Zmin≈0確認
    [chest_bezel.stl, chest_cam.scad, chest_lid.stl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]
2026-07-05 STLを色別フォルダ+個数入りファイル名(_xN)に統一
    - korosuke_print: 単品に _x1 付与(head_front_x1 等9点リネーム)
    - stereo_cam: stl/{orange,red,gray}/ に色分け+_xN(chest/test_case)
    例 orange/chest_plate_x1, red/chest_bezel_x2, gray/chest_pushnut_x4
    - .gitignore: stereo_cam/**/*.stl を追跡(サブフォルダ対応)
    - PRINT_GUIDE: ファイル名を_xNに更新、button個数4→2の誤記修正
    [back_panel_x1.stl, bottom_plate_x1.stl, chest_bezel.stl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]
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2026-07-05 腕・脚・足を水色(単色)に・ベゼルの浮き修正
    - アニメ画像確認: 腕ジャバラ/脚/足は全部「水色」の単色(縞ではない)
    → C_BLUE(#7ec8e3)に統一。navy廃止、arm_ring A/Bは同形状なので
    arm_ring_x18(左右9+9)に統合。folderを light_blue に
    - chest_bezel: ドームがレンズ穴底より下に伸びて小さな傘先(φ13)が
    浮遊していた不具合を修正(レンズ穴を深く貫通)→ 単一ボディ化
    - PRINT_GUIDE更新(light_blue節、arm_ring_B削除)
    [arm_ring_A_x10.stl, arm_ring_x18.stl, chest_bezel_x2.stl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]
2026-07-05 腕の付け根にフレアパーツarm_base追加(案B): 肩側φ44→φ28で自然な蛇腹の裾に
    - arm_base module(SHOW=55)を新設。オス継手φ16上向き+中心配線穴
    - 腕は arm_base×1 + arm_ring×8 のスタック構成に変更
    - STL: arm_base_x2 追加、arm_ring_x18 → arm_ring_x16 に更新
    - PRINT_GUIDE.md 反映
    [arm_base_x2.stl, arm_ring_x16.stl, arm_ring_x18.stl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]
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2026-07-19 ros2: eye_demoのSIGTERM終了時の二重shutdownを修正
    timeout等でSIGTERMを受けるとExternalShutdownException未捕捉で
    tracebackを吐いていた。捕捉+rclpy.ok()ガードで正常終了に。
    (RDK X5実機でM2検証中に発見。ボード側にも反映済み)
    [eye_demo_node.py]
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2026-07-24 monitor v3(挨拶発声/目連動) + systemdサービス群
    - korosuke_monitor.py v3: 人物新規出現で目(happy+視線追従+まばたき)、Web
    「コロ助のセリフ」欄、スピーカーで挨拶WAV再生を統合。MJPEG配信はHTTP/1.0
    維持+img自動再接続(v3.1で固まり回帰を修正)
    - deploy/korosuke-monitor.service: モニタ自動起動(active/enabled済)
    - deploy/korosuke-timekeep*: RTC電池レス対策(fake-hwclock方式で時刻保存/復元)。
    ※真の解はNTP(要ネット)かDS3231 RTCモジュール
    [korosuke_monitor.py]
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2026-07-24 fix(servo): ESP32-S3のLEDCは14bit上限。16bit指定で無出力だった不具合を修正
    - servoWriteDeg/servoSetupを14bit分解能に変更(SERVO_RES=14, duty=us*16384/20000)。
    ESP32-S3のLEDC最大分解能は14bit(公式ESP-IDF docs確認)で、16bit指定は
    ledcSetupが失敗しPWMが出ず、コマンドは受理するがサーボが動かなかった。
    実機で左腕(GPIO4)の動作を確認。boot時にLEDC周波数をログ出力(0=失敗検知)
    - monitor: Web腕テスト(手を振る/バンザイ/下げる+左右スライダー, /armエンドポイント)、
    numpy非推奨警告のログスパム抑止
    [korosuke_monitor.py, main.cpp]
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2026-07-24 fix(servo): 脱力をledcDetachPin+INPUT化(ledcWrite 0では保持トルクが残る問題)
    SG90は閉ループでPWMが来る限り位置保持する。duty0(ledcWrite 0)ではLEDCが
    ピンをLOW駆動し続け脱力しきれなかった。ledcDetachPinでLEDCを切離し
    pinMode INPUTでハイインピーダンス化=PWM完全停止=確実に脱力(保持トルク0)。
    servoWriteDegは再アタッチして脱力後の再通電に対応。
    [main.cpp]
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2026-07-24 fix(monitor): 目デバイスのポート自動検出(ttyACM0/1の入替に対応)
    ESP32抜き差しで/dev/ttyACM0→ttyACM1に番号が変わると目/腕が動かなくなる
    問題を修正。Eyes._ensureをglob(/dev/ttyACM*,/dev/ttyUSB*)で自動検出に。
    (右目の"404"はフレームバッファ乱れの表示グリッチで、ESP32リセット+再描画で解消)
    [korosuke_monitor.py]
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2026-07-24 堅牢化: カメラ/マイクを自動検出(交換でデバイス番号・カード名が変わっても追従)
    - カメラ交換(ELECOM→Logicool C270)で /dev/video0→video1, マイクcard名 Microphone→WEBCAM
    に変化し、映像(index0固定)もSTT(plughw:Microphone固定)も壊れる不具合を修正
    - open_camera(): /dev/video*を走査しフレームが読める最初のデバイスを採用+読取失敗で再検出
    - find_mic_card()/mic_card(): arecord -lからUSB Audioキャプチャのカード名を自動特定
    - apply_mic_hw_gain(): カード自動+制御名(Mic Capture Volume/Capture/Mic)を総当りで最大化
    - 実機確認: C270で cam_ok/audio_ok/yolo/STT/person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
    [korosuke_monitor.py]
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2026-07-24 起動あいさつ/カメラ堅牢化/退室後neutral/シャットダウン音声を修正
    - カメラ: コールドブート時にRDK内部の映像ノードを誤認しないよう USBカメラ(UVC)ノードを優先
    +フレーム検証(size>0)。使用ノードをログ出力。open_cameraはリトライ継続
    - 起動あいさつ: boot_greet()追加 → 起動8秒後に「おはようナリ！」+にっこり+手振り
    - 退室後sleepy対策: 別れ(sad)の後 _settle_neutral で5秒後にneutralへ(待機は起きた顔)
    - シャットダウン音声: speak(block=True)+ /say?sync=1 で再生完了までブロック→途中切れ解消
    shutdown_buttonは固定6秒待ちを撤廃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
    [korosuke_monitor.py, shutdown_button.py]
2026-07-25 音声カード自動テスト&自動修復(起動時+Webボタン)
    - コールドブートのロード順レースでmax98357aが'Invalid argument'で開けなくなる問題対策
    - fix_max98357a.sh: 無音再生でopen検証→ダメなら snd_soc_simple_card 再ロードで再バインド
    - korosuke-audio-fix.service: 起動時(Before=korosuke-monitor)にrootで検証&修復
    - monitor: ensure_audio_card()を起動時に実行+ /audiocheck エンドポイント(sudo経由で修復)
    Web「🔈音声チェック」ボタン+ステータスチップ(spk_ok)追加。state/eventsにspk_ok
    - sudoers: sunriseが修復スクリプトのみNOPASSWDでsudo可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
    [korosuke_monitor.py]
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2026-07-25 docs: 電源/USBトラブルシュートを追加(緑LED不点灯・USB/ネット不良=電圧降下)
    - USB-C電源ケーブル/アダプタの能力不足=under-voltageが根本原因、と診断・対処を体系化
    - 公式要件(5V/3A以上,PC給電禁止,認定ケーブル)+dmesg signature(cable is bad/error -71)
    - STAGE3の資料リストにもリンク追加
2026-07-25 STAGE3: アーキをMermaid図化 + Known issues/failure recovery + 審査要件対応表
    - §5 ArchitectureをMermaid(GitHub自動描画)に。BPU=知覚/CPU=言語の分担を明示、ROS2グラフも参照
    - §8 Known issues, limitations & failure recovery(LLM遅延/電源USB/音声race/RTC/bipedal)+安全終了
    - §9 Stage-3 requirement coverage表(審査員が確認しやすく)+ベンチ表+BPU加速の証明
    - デモ動画3-7分/LICENSE/community post/showcase PR を TODO として明示
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2026-07-25 提出物整備: README刷新(Stage3 Quick Start) + ショーケースdoc Stage3追記 + community post下書き
    - README.md: Stage3向けに全面更新。正確なQuick Start(clone→build→run, 秘密情報なし,
    ROS2 launch/モノリス両対応), 実態に合うBOM/構成/docs索引。旧server/APIキー記述を削除
    - docs/KazukiMurata-Project-Korosuke.md: Stage completed=3, Stage 3 Launch節を追記
    (STAGE3/デモ動画/ROS2/MAX98357A自作ドライバ/BPU-LLM検証/安全終了)
    - docs/community_post_stage3.md: Discord短縮版+フォーラム長め版の告知下書き
    - ROADMAP M5: 現状(showcase/README/ROS2/failure-recovery完了, 3-7分動画+PRが残)に更新
    Co-Auth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
2026-07-25 修正: ジェスチャ反応がreact_greetトグルを無視して喋る問題
    - detect_gesture が cooldown/present のみ判定で、反応OFFでもバンザイ等を喋っていた
    - react_greet(入退室で挨拶)OFF時はジェスチャ反応もしないよう条件追加
    - (撫で=react_speech, モーション=無効, 挨拶/話しかけ=既にトグル準拠 は問題なし)
    [korosuke_monitor.py]
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2026-07-26 docs: 未実装機能の過大表現を是正(口2軸リップシンク/二足歩行/背中の刀)
    - STAGE3 §8: 未実装(2軸口・リップシンク/QDD二足歩行/背中の刀)を明記
    - ROADMAP G2/G4: 首追従=eyes-onlyで見送り, リップシンク=未実装 と正直に
    - KazukiMurata: voice_node(TTS)/expression_node(eyes)に修正, BOMリンク切れ修正
    - PROPOSAL: 冒頭に「計画であり出荷物ではない/見送り項目あり」注記, 404リンク修正
    - STAGE3 §7 BOMは重複回避でPROPOSAL §3.1参照+as-built差分のみ
2026-07-26 ROS2: 対話/音声を完全オンデバイス化(クラウド撤去) + READMEに未実装表
    ROS 2グラフのdialogue/voiceが出荷版と別物(クラウド)だった問題を是正:
    - dialogue_node: Claude haiku(api.anthropic.com/APIキー)を撤去し、
    モノリスと同じ TinySwallow-1.5B(llama.cpp, CPU)へ移植。完全オンデバイス。
    - voice_node: VOICEVOX(別サーバ)を撤去し、同じ Open JTalk へ移植。
    - personality.py: LLM_PERSONA/few-shot/モデルパス/Open JTalk設定を集約。
    - serial_bridge: 許可感情に thinking/dead を追加(考え中の目が届かないバグ修正)。
    → これで「no cloud / no API key」原則にROSグラフも準拠。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
    [dialogue_node.py, personality.py, serial_bridge_node.py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]
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2026-07-26 fix(monitor): 英語STT切替でSTTが止まる不具合を修正 + 英語few-shot強化
    - STT: 要求言語(req)と実ロード言語(lang)を分離。英語モデル未導入で
    日本語にフォールバックしても「要求は処理済み」と扱い、毎ループの
    誤「言語切替」検知→arecord無限再起動→STT停止 を解消。
    - さらに実モデルが変わらない切替(en→ja据え置き)では認識器を再ロード
    せずreqだけ更新して録音継続=切替時の無音を無くした。
    - 英語モードのLLM応答が食べ物等で日本語に逸脱するのを抑えるため、
    LLM_FEWSHOT_EN にコロッケ/日本語入力→英語返答の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
    [korosuke_monitor.py]
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2026-07-26 fix(monitor): 言語切替をヘッダ🌐と一括ボタンで一貫化+現在選択を表示
    - ヘッダ🌐と「🌐一括/All」は同じ setAllLang 経路=同一効果に統一。
    - applyUiLang が全インジケータを同期: ヘッダ文言 / 一括ボタンの選択中
    ハイライト(button.on) / 表示言語ドロップダウン値。両方から変えても状態が一致。
    - 「一括/All」は現在どちらの言語かをボタンのハイライトで表示。
    [korosuke_monitor.py]
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2026-07-26 slides/docs: RDK X5を強調+D-Roboticsロゴ, 配線図を英語化, アーキ図のI2SをRDK由来に修正
    - 接続図(wiring.md/jpg/png)を英語化。RDK X5をmainクラスで大きく強調し、
    D-Roboticsロゴ(白)をノード内に表示。
    - スライド02(Architecture): I2Sスピーカは RDK X5→MAX98357A→φ50 が正。
    ESP32-S3はeyes/armsのみに修正。
    - スライド03(Connections)のRDKにもロゴ。デッキJPG再出力。
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2026-07-27 feat(hardware): 胴体v2 — SG90ネジ止めロープ牽引・中段デッキ・天面開口・胸カメラ・下出し配線
    要件対応:
    - SG90x2: 中段デッキ下吊りLブラケット(左右共通)。窓23.1x12.5・タブ穴ピッチ28.6(図面裏取り)。
    軸オフセット5.55mm相殺で出力軸=ロープ穴直下。デッキφ8穴がロープガイド兼用。
    引き方向: ホーン12時=緩み、内側回し=引き(左右逆・ESP32で反転)
    - RDK X5ベイ: v1互換縦置きレール + 底板にUSB窓56x24(電源/通信TypeC/カメラ/ESP32を下出し)
    - モバイルバッテリー: 背面縦置きトレイ(62x24既定・パラメータ化)+ベルクロスロット
    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
    [bottom_plate_v2_x1.stl, cam_bezel_x1.stl, foot_base_v2_x1.stl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]
2026-07-27 feat(hardware): 胴体v2の印刷データ一式をv2/フォルダに整備 + 印刷性の欠陥2件を修正
    印刷性修正(スライサ検証で発覚):
    - デッキ受けボスが宙吊り(z=86起点)でサポート必須だった → 底から立つ全高柱(z=0-102)
    +壁連結リブに変更。底板に柱ノッチx4を追加(サポート完全不要に)
    - servo_bracket SHOW=4が組付け向きのままだった → L字を寝かせた印刷向きに修正
    v2/フォルダ(印刷データ一式):
    - v2/orange: jacket_shell_v2, bottom_plate_v2, top_lid
    - v2/gray: mid_deck, servo_bracket(x2), foot_base_v2
    - v2/red: cam_bezel
    - v2/PRINT_GUIDE_V2.md: 色別プレート・個数・向き・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
    [bottom_plate_v2_x1.stl, cam_bezel_x1.stl, foot_base_v2_x1.stl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]
2026-07-27 fix(hardware): 胴体v2 — 全体表示で発覚した外装バグ2件を修正 + 断面表示をCUTフラグ化
    - プレビューの断面カットが既定ONで「半分しか見えない」→ CUT=false を既定に
    (断面が見たいときだけ -D CUT=true / エディタで CUT=true)
    - 胸カメラのボス/レンズ窓の向きが外向きに反転していた(rotate符号ミス)
    → ボスは内壁から内側へ、レンズ窓は貫通+外広がりすり鉢(曲面全域カバー)に修正
    - スピーカー座リング(φ58)の左右端が湾曲壁を突き破っていた
    → 内面コーンとの交差でトリムし全周を壁に融着。音抜きφ44+落とし込み+結束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
    [jacket_shell_v2_x1.stl, torso_v2.scad]
2026-07-28 feat(hardware): SG90ブラケットにコの字クレードル追加 + MOCKUPフラグ(FreeCADで搭載部品も表示)
    - servo_bracket: 板+窓だけだった保持を「コの字」(底+左右壁2.7mm)で本体を抱える形に強化。
    SG90ケーブルは軸と反対(+X)壁下のスロットから引き出し。向き不変(軸=ロープ穴直下)
    - MOCKUP=true で RDK X5ケース/バッテリー/ブレッドボード/SG90 のゴーストを実体出力
    (FreeCAD向けCSG: openscad -o preview.csg -D MOCKUP=true -D SHOW=0 torso_v2.scad)
    - SG90ゴーストをクレードル実位置に更新・色分け
    - v2/gray/servo_bracket_x2.stl 再生成、ブラケット画像更新
    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
    [servo_bracket_x2.stl, torso_v2.scad]
2026-07-28 feat(hardware): SG90を腕穴直下のシェル一体「コの字タワー」に変更(実機レイアウト準拠) + モックアップ調整
    - servo_tower: 床から立つ中空タワー(x=±44-79)の頂部にコの字スロット(上開放)。
    サーボは上から落とし込み→前面から付属M2x2。軸側の端を胴中心側に(左右で逆)。
    ロープ: 腕穴→天面Vノッチ→ホーンへほぼ一直線(ユーザー実機写真の配置を踏襲)
    - mid_deck: タワー逃げの側面切欠き(旧デッキ吊りのロープ穴/M3は廃止)
    - bottom_plate_v2: タワー壁足元の逃げ3矩形/側(内側の床は残す)
    - ghosts: ブレッドボード削除(ESP32-S3+ブ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
    [bottom_plate_v2_x1.stl, jacket_shell_v2_x1.stl, mid_deck_x1.stl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]
2026-07-28 fix(hardware): サーボタワーv2.1 — ホーンを腕穴位置へ(サイズ再計算) + 腕穴との干渉解消
    指摘対応「胴体から手が出る穴の位置にサーボホーンが来る必要がある」:
    - 軸(±68, z=112)・ホーン15mm真上で先端=(±68, z=127)=腕穴中心高さ。
    ロープは蛇腹中心軸からほぼ直結。引きストローク約22mm(120°)
    - 軸側の端を【外側=腕穴側】に向ける配置に反転(本体は内側へ→壁と干渉せず。
    スロット23.3x12.5 vs 本体22.7x12.1=クリアランス0.4-0.6で適合を計算確認)
    - タワーをx44-70に縮小 → 腕穴カット(x>70.5)との交差ゼロ(穴内の"十字"解消)
    - 固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
    [bottom_plate_v2_x1.stl, jacket_shell_v2_x1.stl, torso_v2.scad]
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2026-07-28 fix(hardware): SG90十字ホーン対応タワーv2.2(掃引干渉解消・数式検証) + RDK上下+5mm + スピーカーφ50確認
    SG90機構を正しくモデル化(指摘対応):
    - 十字ホーンは軸まわり半径≈16mmで掃引 → 前v2.1は軸x68で外壁を突き破っていた
    - 軸を(±58,126)へ移動し、ホーン面をクレードル背面の後ろ(y3)に配置
    =十字はタワー後方で旋回しタワーと不干渉。掃引円は外壁4.7mm/デッキ5.0mmクリア(計算検証)
    - クレードルはシェル側壁に融着(deck上z106-136)+bore下ペデスタル。床/脚/底板に触れず脚と非干渉
    - 内側タブ(x±38, 掃引円外)にM2×1。軸端を外=腕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
    [bottom_plate_v2_x1.stl, jacket_shell_v2_x1.stl, mid_deck_x1.stl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]
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2026-07-28 fix(hardware): mirror()を全廃しFreeCAD CSGを開けるように(Input shape is null の真因)
    - FreeCADのCSGインポータは鏡像変換(負スケール行列)を表現できず"Input shape is null"落ち
    - 左右対称パーツを mirror() → 座標の符号反転(xbox/sgヘルパ)に書き換え(STL形状は不変):
    servo_tower_at(sg) / mid_deckのタワー逃げ / ghostsのSG90
    - torso_v2_assembly_cut.csg / preview.csg をmirror無し版で再生成(FreeCADで直接開ける)
    [torso_v2.scad]
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2026-07-28 fix(hardware): SG90が確実に入るよう実物寸法で検証・干渉解消(freecadcmd)
    「そもそも入るのか/干渉が気になる」への回答:
    - 実物SG90/十字ホーンをfreecadcmdで実測: 本体13.64x22.7x22.5, 十字ホーン旋回半径17.9
    - 軸をx58→x56へ(ホーン半径18でも内壁≈78.7と約4mmクリア)
    - ★検証: SG90×2/ホーン×2とも「内壁コーン外へのはみ出し=0.00cm3」=完全に胴内(合格)
    - サーボ台: 本体ポケットをz110-150に(本体全高を収容=クレードル床と非干渉)、
    十字ホーン旋回クリア(軸まわり半径19.5をy≧-2で除去=ホーンが台に当たらない)
    - SG90タブはホーン側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
    [shell_v3.stl, torso_v3.FCStd, torso_v3.scad]
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2026-07-28 refactor(hardware): 臓物を全てShell側に + Bottomは胴体を載せる台に + Shell底面を開放
    - Shell底面のバグ修正: 内側コーンを貫通させ底面を開放(3mmの床が残っていた)
    - 方針変更「臓物は全て胴体に付ける/Bottomは胴体を載せるだけ」:
    - Shellに case_cage 追加(RDK前ストッパ/仕切り/電池後ストッパ・壁融着・両面テープ・ケーブル穴)
    → RDK/バッテリーは胴体側で保持
    - bottom_v3 を「載せ台」に簡素化: φ158フランジ(胴裾が載る)+位置決めリム+脚バー(脚ボス/M3)
    +大穴。電子部品ガイドは撤去
    - shell/bottom STL・FCStd再生成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
    [bottom_v3.stl, shell_v3.stl, torso_v3.FCStd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]
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2026-07-28 feat(hardware): 前面レイアウト再構成 — 長方形開口を前面へ + 上にカメラ + スピーカーのコの字ホルダ
    - 旧背面ハッチ(長方形70x65)を前面へ移動=前面の長方形開口
    - カメラ台を長方形の上(z=108)に配置(その上にカメラ)
    - speaker_mount 追加: φ50x18.5スピーカーがすっぽり入るコの字ホルダ(上開放で落とし込み・
    前へ音抜きφ44→長方形開口から前へ鳴らす・結束バンド穴)。専用グリルは廃止
    - スピーカーゴーストを前向きに修正、SPK_Z=50。FCStd再生成
    [shell_v3.stl, torso_v3.FCStd, torso_v3.scad]
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2026-07-28 fix(hardware): 前面ディスプレイ長方形を元の7x10cm(70x100mm)に復元 + カメラをz136へ
    - 誤って縦72mmに縮めていた前面長方形を、v2ハッチ同寸の70x100mm(7x10cm)に戻す
    (HATCH_H=100, HATCH_Z=20 → z20-120)
    - カメラをz112→z136へ再度上げ、ディスプレイ上端(120)と1mm離隔。腕穴(127)は側面で別角度=非干渉
    - FreeCAD .py のカメラ/スピーカー位置を新レイアウトに同期。freecadcmdでSG90×2壁貫通=0.00cm3を再確認
    - shell STL / FCStd / プレビュー(front/left/cut)更新
    [shell_v3.stl, torso_v3.FCStd, torso_v3.scad]
2026-07-28 fix(hardware): スピーカー音抜き穴を廃止(側壁を塞ぐ) + 全搭載物を壁貫通ゼロに
    - スピーカー: 音抜き穴(φ44貫通)を廃止=側壁は塞いだまま。ホルダは上から落とし込むU字
    クレードル(壁側solid back)、両面テープで固定(大体でOK)。位置を側面の真横(SPK_Y=0)へ移し、
    ディスク縁を内壁にインセット→はみ出し 0.00cm3(以前は前寄りで壁を突き抜けていた)
    - カメラ基板も同原理で2mm奥へインセット+外形を壁でクリップ→はみ出し 0.38→0.00cm3
    - freecadcmd全チェック: SG90x2/ホーンx2/スピーカー/カメラ すべて0.00cm3(完全に胴内)
    - shell S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
    [shell_v3.stl, torso_v3.FCStd, torso_v3.scad]
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2026-07-30 fix(hardware): 差動ベースv3 — ドライブポッド方式(v2の「タイヤを付けた状態で入れられない」を解消)
    ユーザー指摘: v2はサーボ固定後にタイヤを付ける空間が無く、FS90R-Wの中心ネジにも工具が届かない。
    対策: アーチ+隔壁を「ドライブポッド」としてベースから分離。
    - 机上で完組み(サーボ→隔壁M2×2 → タイヤをスプラインへ+中心ネジ) → ポッドごと上から
    デッキ開口(51..72 × ±32)へ落とし込み → M3×4を上からセルフタップ。交換=ポッド脱着
    - 左右は同一部品(印刷2個・左は180°回転で取付=ミラー印刷不要)
    - フラン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
    [base_diff_v3.FCStd, base_diff_v3.scad, base_diff_v3.stl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]
2026-08-13 feat: 残作業を一括反映 — 胴体ディスプレイ/ミニコロ助/SG90 CAD参照/監視スクリプト更新
    - firmware/corosuke_display + tools/display_send.py + docs/esp32_4827s043_display.md:
    Sunton ESP32-4827S043R(CYD)にRDKカメラ映像をUSBシリアルで表示する胴体ディスプレイ(M0-M2実機OK)
    - firmware/mini_korosuke + docs/mini_korosuke_design.md + tools/mini_voice_gen.py + assets/:
    ESP32-S3単体・完全オフラインの派生機「ミニコロ助」(目8種/なで/顔検出/事前生成WAV)
    - tools/rdk_display_flash.sh / rdk_display_start.sh: RDK側の書き込み/起動ヘルパ
    - hardware: SG90/十字ホーンのCAD参照(sg90-servomotor-arms snapsh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
    [SG90_Arm_01_Custom.f3d, SG90_Arm_01_Custom.step, SG90_Arm_02_Custom.f3d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]
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2026-08-13 docs(blog): 太字が崩れる2箇所を修正(GitHub MDは「)**+日本語」で閉じ太字を認識しない)
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2026-08-13 docs(stage3): 配線図(How it all wires together)を§3に追加 + 動画リンク切れを修正
    - wiring.mdの英語mermaid配線図(電源2系統/共通GND/ピン番号)を§3末尾に掲載
    - リンク切れ修正: 重い元動画(28/33MB)はgitignore除外のままリポジトリに無かった
    → 720p圧縮版(0.5/0.7MB)を korosuke_demo_10s.mp4 / arm_rope_pull.mp4 としてコミットし
    STAGE3の3箇所のリンクを差し替え(GitHubのblobページでクリック再生可)
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2026-08-13 docs: body_ver2.jpgを90°右回転し横長2枚並びに + ブログ文言修正
    - body_ver2.jpg: 縦4032→横4032x2268に回転。ブログ(49%+49%)/STAGE3(49%+49%)で
    head_v1と同じ高さの横並び1段に収まる
    - 「3Dパーツは 店長・村田がAIと共同製作。」に変更
    - 「各部品の筐体構成は下記。」「頭: 半球二つ」に変更
2026-08-13 docs: パイプライン図の誤解を修正 — ESP32-S3は1台(目2+腕2を兼務)を1ノード+分岐で表現(STAGE3/ブログ両方)
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2026-08-13 docs(blog): 英語版 intro_en.md を新規作成 + 日英相互リンク + 「各部品の詳細は下記。」に修正
    - intro_en.md: 日本語版と同構成の英語完全版(はじめに/背景/HW+SW図/製作過程/あとがき/トラブルシュート)
    5分プレゼン(4分トーク+1分デモ)向けに簡潔化
    - intro_ja.md: 冒頭に English version へのリンク、文言修正
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2026-08-13 docs: スライド/原稿をintro_en.md準拠に刷新 + built by Robostadion修正 + 治具にブレッドボード/ジャンパワイヤ追加
    - talk_5min.html: 章立てをブログと同期(Title/Introduction/Background/HW/SW/Build/Afterword/Demo)
    写真もブログと同じ(head_v1/body_ver2等)。built by Robostadion に修正
    - talk_5min_script_en.md: 新スライド構成に合わせて全面改稿(時間配分維持・削除依頼の一文は不使用)
    - intro_ja.md Key messages: built at→by Robostadion
    - 製作治具: ブレッドボード(小型)+ジャンパワイヤをブログ日英+READMEに追加(BOM補完)
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2026-08-13 fix(monitor): 手元カメラ表示中は本文をパネル幅ぶん右に寄せて隠れないように(リサイズ追従)
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2026-08-13 fix(monitor): パッチ事故で欠落したサーバ処理・main部をbbab06eから復元(全機能維持: kact/手元カメラ/resize/HTTPS/auto既定)
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2026-08-13 fix(display): タッチが無反応だった根本原因を修正 — drain_espのTOUCH/CTL処理が エスケープ不一致でパッチ空振りしていたのをEditで確実に投入。言語ボタン+くすぐったい反応が有効に
    (同梱: 言語ボタン常時表示/回転対応overlay/座標ヒット判定/tickle実装/ファームTOUCH座標送信)
    [display_send.py, main.cpp]
2026-08-13 fix(display): write_timeout=2でESP32ハングを検知→シリアル再接続(DTRリセット)で自動復旧
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2026-08-14 fix(display): 映像ソース(MJPEG)切断からの自動復旧 + シリアル再接続時のパネル情報リセット
    モニタ再起動でMJPEGが切れると cap.read() が永久に失敗しログ凍結・NO SIGNALの
    まま止まる実障害(2026-08-14 04:32)を修正。新フレーム5秒途絶で開き直し、復帰まで
    リトライ。シリアル再接続時はパネル情報をCLI既定へ戻す(画面差し替え対応、新FWは
    SIZE申告で即再適応)。実機で モニタ再起動→自動復帰 を確認済み。
    [display_send.py]
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

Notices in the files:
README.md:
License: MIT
